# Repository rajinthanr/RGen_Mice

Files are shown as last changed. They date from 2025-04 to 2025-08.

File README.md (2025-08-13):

# 🐭 Open Source Micromouse Project

Welcome to the official repository of our **Open Source Micromouse** - a fast, intelligent, and compact maze-solving robot developed from scratch by [rajinthan](https://github.com/rajinthanr). This project aims to document every step of the design and development process, making it easy for students, hobbyists, and engineers to learn and contribute.

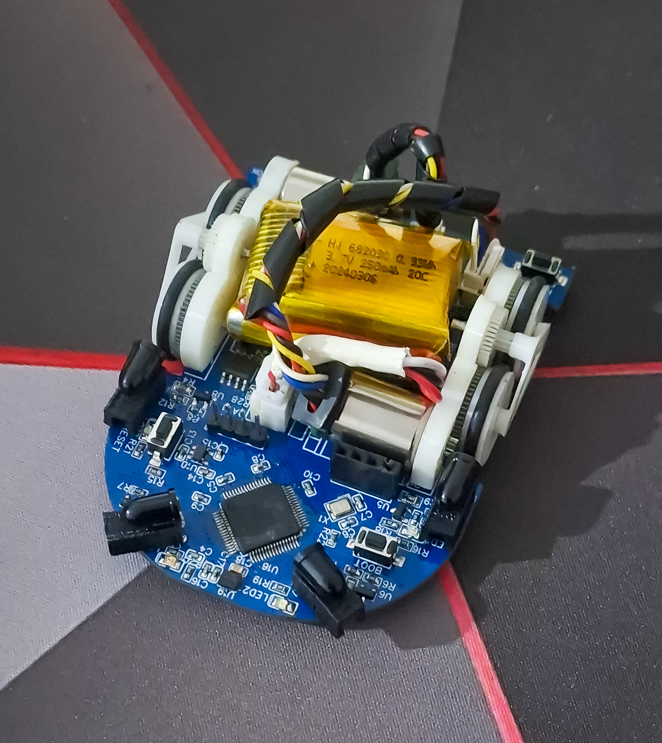
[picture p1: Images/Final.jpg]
Micromouse Design


---

## 🚀 Project Goal

To design and develop a **four-wheel differential drive Micromouse robot** capable of solving mazes efficiently with smooth acceleration, encoder feedback, and intelligent path planning — while maintaining openness for community learning and contribution.

---

## 🧭 Table of Contents

- [🔍 Research & Reference Designs](#-research--reference-designs)
- [🧩 Component Selection](#-component-selection)
- [📐 Mechanical Design](#-mechanical-design)
- [⚙️ Drive System](#️-drive-system)
- [🔌 Electronics & PCB Design](#-electronics--pcb-design)
- [📦 Firmware Development](#-firmware-development)
- [🧠 Algorithms & Strategy](#-algorithms--strategy)
- [🖥️ Simulation](#️-simulation)
- [📸 Gallery](#-gallery)
- [📚 Resources](#-resources)
- [🤝 Contributing](#-contributing)
- [📜 License](#-license)

---

## 🔍 Research & Reference Designs

Before jumping into development, we explored multiple Micromouse designs, performance benchmarks, and open-source efforts.

- [Ukmars](https://ukmars.org/)
- [Greenye](https://youtube.com/@greenye?si=StKEDgfJgn1EC-rX)(Good youtube channel)
- [Micromouse Online Handbook](https://micromouseonline.com/)
- [Speed Profile](https://micromouseonline.com/2017/08/03/micromouse-hard-acceleration/)

### 📄 Design Inspirations

- Green-Giant

*Reference images:*

| Reference Design 1 | Reference Design 2 |
|---|---|
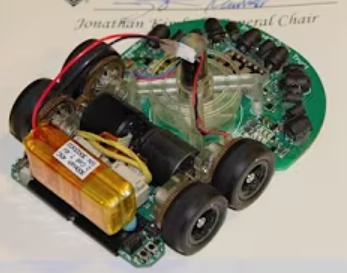
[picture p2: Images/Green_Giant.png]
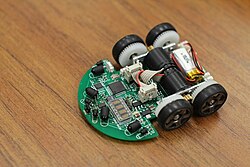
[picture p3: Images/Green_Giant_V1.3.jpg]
|  |  |

---

## 🧩 Component Selection

Every part was chosen with precision to balance performance, weight, and efficiency.

| Component | Description | Datasheet |
|---|---|---|
| MCU | STM32F405 (ARM Cortex-M4) | [Datasheet](https://www.st.com/resource/en/datasheet/dm00037051.pdf) |
| Motors | Coreless Motor 1215 with quadrature magnetic encoders | [Datasheet](//) |
| Encoders | Builtin quadrature magnetic encoders | - |
| IMU | ICM-42688 | [Datasheet](https://invensense.tdk.com/download-pdf/icm-42688-p-datasheet/) |
| Sensors | TEFT4300 IR sensors | [Datasheet](https://www.digikey.com/en/products/detail/vishay-semiconductor-opto-division/TEFT4300/1681175) |
| Power | 2S Li-po 250mAh | - |

> 💡 *Includes datasheets for all components in the `Research/Datasheets` folder.*
---

## 📐 Mechanical Design

- Designed in **Onshape**
- Lightweight 3D printable chassis
- Wheel size, placement optimized for turn radius

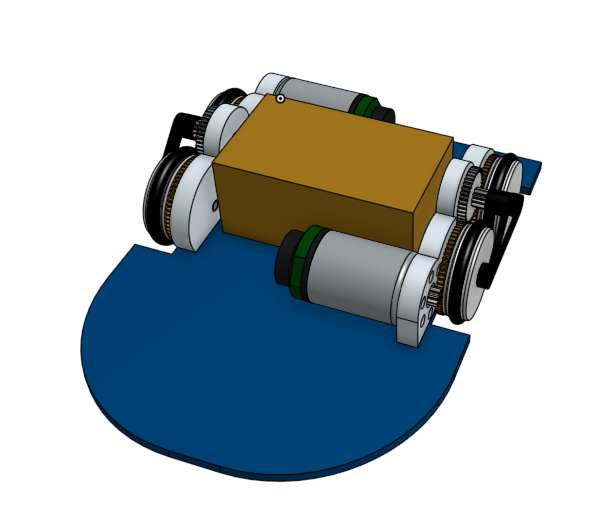
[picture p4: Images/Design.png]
Chassis render


> 💡 *Includes STL files for all parts in the `Design/` folder.*

---

## ⚙️ Drive System

- **Differential drive** with PID-based velocity control
- Closed-loop motor control using encoders
- Acceleration curve implemented to avoid overshoot

### Drive Tuning

- ✔️ Encoder feedback integrated
- ✔️ PWM control through timer
- ✔️ Slew rate limiter for smooth turns

### Design Itterations

|V1|V2|V3|
|----|----|----|
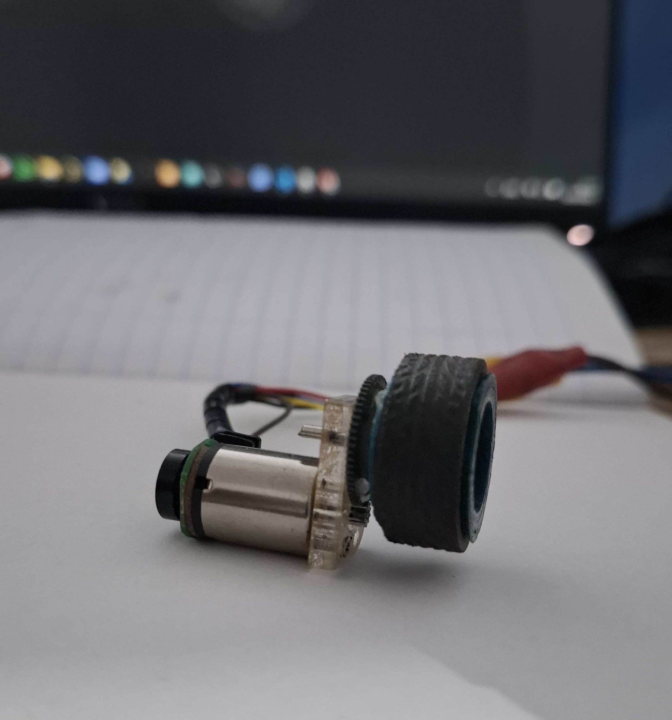
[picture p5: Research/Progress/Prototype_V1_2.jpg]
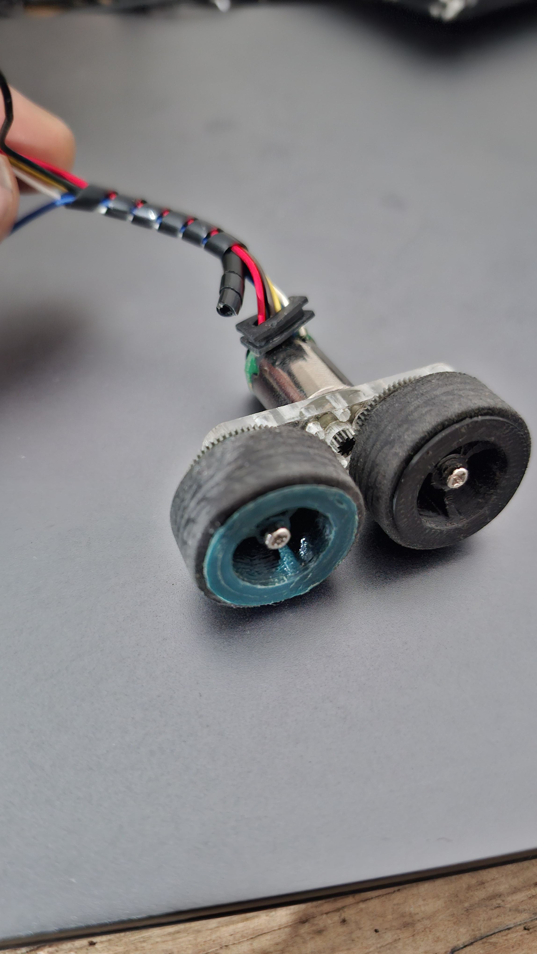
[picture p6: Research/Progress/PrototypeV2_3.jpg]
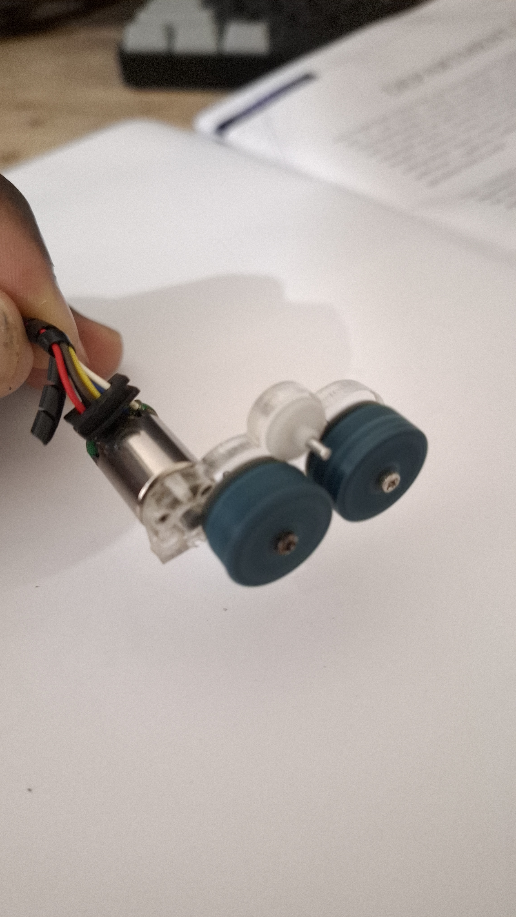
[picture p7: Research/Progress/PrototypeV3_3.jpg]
||||

---

## 🔌 Electronics & PCB Design

Designed using **Easy EDA** - free tool for beginners, our custom 2-layer PCB includes:

- STM32F405 MCU
- Power ICs
- Motor, Encoder and Power connectors
- Motor drivers (DRV8833)
- Programming header (SWD)

| Design | Soldered |
|---|---|
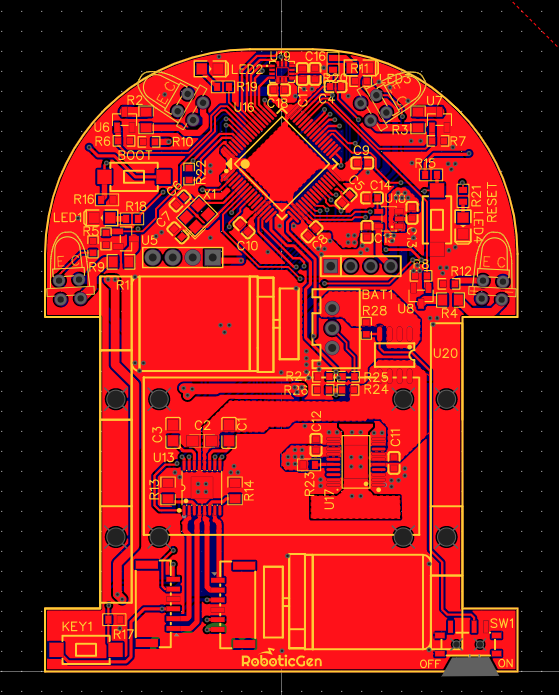
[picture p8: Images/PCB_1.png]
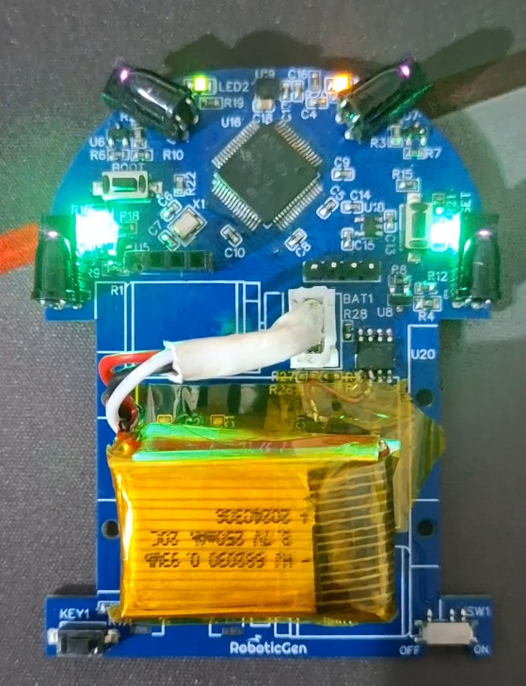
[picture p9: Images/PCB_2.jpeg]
|  |  |

```bash
# PCB files and Gerbers:
PCB/
├── BOM.csv
├── micromouse.sch
└── gerbers/

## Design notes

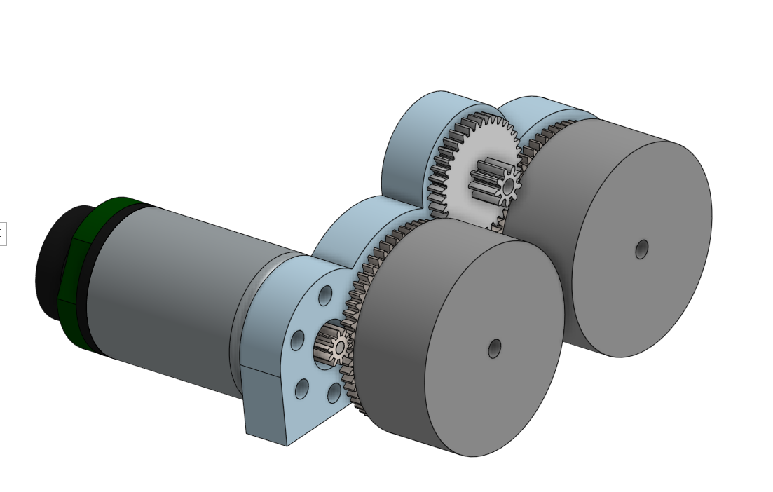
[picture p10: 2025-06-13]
Research/Progress/3D DesignV3.png

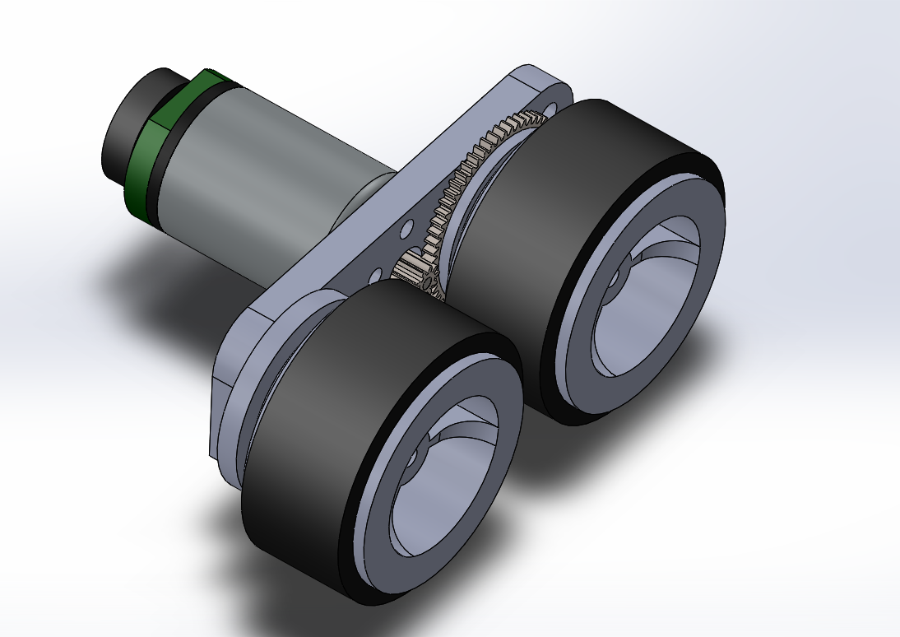
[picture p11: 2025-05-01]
Research/Progress/3D DesignV2.png

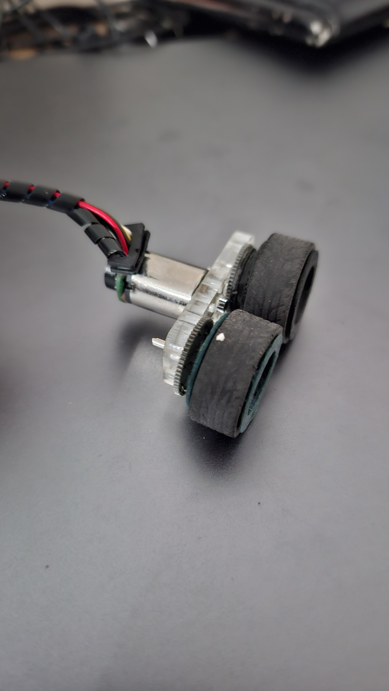
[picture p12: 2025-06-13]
Research/Progress/PrototypeV2_1.jpg

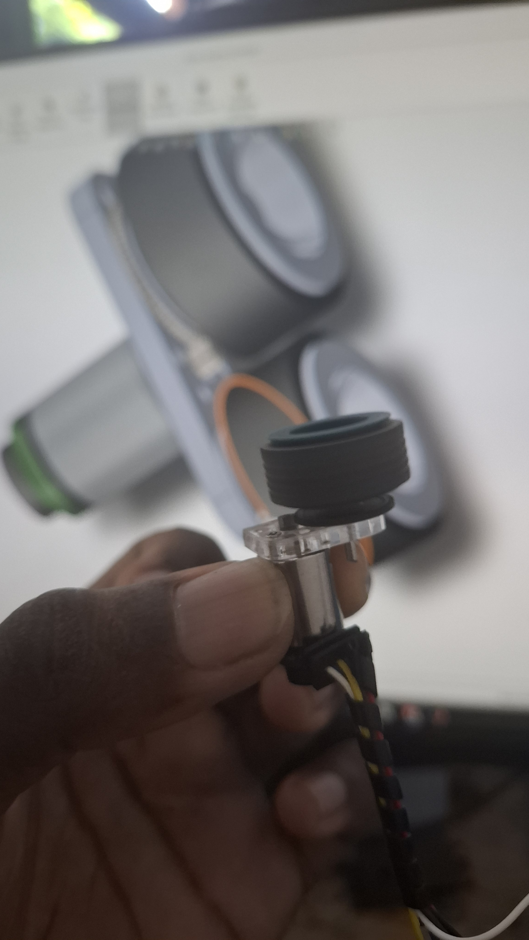
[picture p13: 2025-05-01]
Research/Progress/Prototype_V1_1.jpg

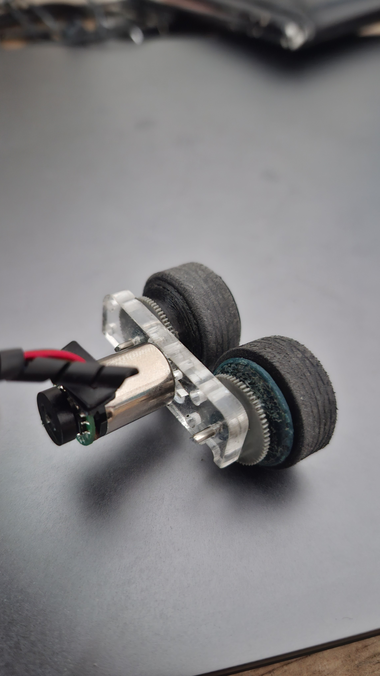
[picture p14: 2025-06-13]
Research/Progress/PrototypeV2_2.jpg

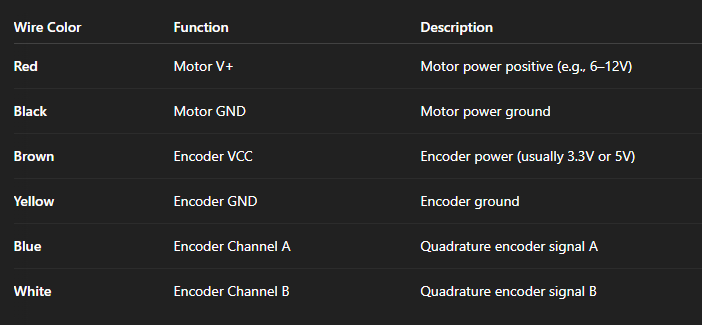
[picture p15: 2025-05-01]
Research/Datasheets/image.png

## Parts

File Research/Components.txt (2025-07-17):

MCU
    *stm32f405
        +have enough pins and speed for our micromouse
        -no builtin Wireless debugging options available
        +reliable
        IDE -> stm32CubeIDE

    esp32s3
        -pins are limited
        +builtin BT&WiFi available for debugging
        IDE -> esp-idf & ArduinoIDE

IR
    Emitter
        *SFH4545  (Half angle = 5°)
    Recievers
        TPS601A  (Angle of Half Sensitivity= ±10°) - many japanese mice used this one but it's been discontinued now
        LTR4206E (Angle of Half Sensitivity= ±20°)
        *TEFT4300 (Angle of Half Sensitivity= ±30°) - commonly used one

IMU
    LY3200ALH (Analog Gyro - Single Axis - Rate noise density 0.074 dps/√Hz) - too old, noisy
    (+)ICM-20948 (9-Axis) - good one
    *(+)ICM-42688 - latest (32kHz DRO, low noise)
    ICM-45686
    ADXRS642
    ADXRS300 and ADXRS610
    (+)ASM330LHH (2020 by ST Microelectronics) - 3kHz sampling rate & reliable

Motor Driver
    TC4427 (Mosfet Driver) - need of p-mos means lack of efficency
    zxmhc3f381n8tc (3A Mosfet H-Bridge) - high current rating but bit harder to use
    *DRV8833 (1.5A) - easy to use and compact
    TB67H420FTG (9.0A) - overkill for our mouse and too many pins to solder

Motors
    N20 geared Motors with magnetic encoders
        +Builtin encoders
        +cheaper
        -not accurate
        -not small enough

    Faulhaber
        +Builtin encoders
        -too expensive
        +much accurate
        +Reliable
    
    Steppers
        -Too bulky and power hungry
        -too slow for micromouse
        +Higer Accuracy

    *Coreless Motor 1215 with quadrature magnetic encoders
        +Builtin encoders
        +cheaper
        +smaller
        -not reliable (but enough for our purpose)

Encoders
    It's better to use builtin encoders

Display
    HCMS-2903 - speed and compact but no of characters are limited, expensive
    *SSD1306 (0.96" OLED) - very slow, cheap
    SSD1306 (0.91" OLED) - this is also enough and compact

Power ICs
    *TPS76850 (5V 1A) - low dropout (230mV)
    *TPS73633 (3V3 400mA) - low dropout (76mV)
    AMS1117 (3V3 800mA) - Dropout voltage is high (1V)

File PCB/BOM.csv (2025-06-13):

ID | Name | Designator | Footprint | Quantity | Manufacturer Part | Manufacturer | Supplier | Supplier Part | Price
1 | JST 3 pin | BAT1 | 3PIN_2.54_MM_JST_XHP_JST_CONNECTOR_FOR_DC_SOCKET | 1
2 | 0.01u | C1 | C0805 | 1
3 | 1u | C2 | CASE-A_3216 | 1
4 | 0.1u | C3 | C0805 | 1
5 | 2.2u | C4,C5,C16 | C0603 | 3
6 | 22p | C6,C7 | C0603 | 2
7 | 100n | C8,C9,C10 | C0603 | 3
8 | 100nF | C11,C13,C14,C15 | C0603 | 4 | CA45-A-35V-0.1UF-K | CEC(振华新云) | LCSC | C2976900 | 0.114
9 | 10u | C12 | C0603 | 1
10 | 0.1u | C17 | C0603 | 1
11 | 10n | C18 | C0603 | 1
12 | SW | H1 | HDR-TH_4P-P2.54-V-M | 1 | B-2100S04P-A110 | Ckmtw(灿科盟) | LCSC | C124378 | 0.046
13 | COM | H2 | HEADER-HEADER-FEMALE-2.54_1X4 | 1 |  |  | Private
14 | BOOT | KEY1 | KEY-SMD_L6.0-W3.6-LS8.3-L | 1 | Switch,3*6*5Plastic head,260G, 0.25mm,SMD | BBJ | LCSC | C71854
15 | KEY1 | KEY2 | KEY-SMD_L6.0-W3.6-LS8.3-L | 1 | Switch,3*6*5Plastic head,260G, 0.25mm,SMD | BBJ | LCSC | C71854
16 | RESET | KEY3 | KEY-SMD_L6.0-W3.6-LS8.3-L | 1 | Switch,3*6*5Plastic head,260G, 0.25mm,SMD | BBJ | LCSC | C71854
17 | PWR | KEY4 | SW-TH_6P-L5.8-W5.8-P2.00-LS4.5-TR | 1 |  | ReliaPro | LCSC | C56857
18 | IO18 | LED1,LED2,LED3,LED4 | LED0805_BLUE | 4 | D-B080508B1-KS2 | 方舟 ARKLED |  | C108412 | 0.019
19 | 10 | R1,R2,R3,R4 | R0805 | 4
20 | 10K | R5,R6,R7,R8 | R0603 | 4
21 | 1k | R9,R10,R11,R12 | R0603 | 4
22 | 100m | R13,R14 | R0805 | 2
23 | 10K | R15,R16,R17 | R0603_SMD-CRCW060327R0FKEA | 3
24 | 1K | R18,R19,R20,R21 | R0603_SMD-CRCW060327R0FKEA | 4
25 | 0 | R22 | R0603 | 1
26 | 250k | R23 | R0603_SMD-CRCW060327R0FKEA | 1
27 | 100k | R24 | R0603 | 1
28 | 47K | R25 | R0603 | 1
29 | 47k | R26,R27 | R0603 | 2
30 | FL | U1 | SFH4545 | 1
31 | L | U2 | SFH4545 | 1
32 | R | U3 | SFH4545 | 1
33 | FR | U4 | SFH4545 | 1
34 | AO3400NSA | U5,U6,U7,U8 | SOT-23-3_L2.9-W1.3-P1.90-LS2.4-BR | 4 |  | DOWO(东沃) | LCSC | C5456620 | 0.044
35 | FL | U9 | TEFT4300 | 1
36 | L | U10 | TEFT4300 | 1
37 | R | U11 | TEFT4300 | 1
38 | FR | U12 | TEFT4300 | 1
39 | DRV8833PWP | U13 | TSSOP-16_L5.0-W4.4-P0.65-LS6.4-BL-EP | 1 |  | TI(德州仪器) | LCSC | C50506 | 0.705
40 | MOTA | U14 | CONN-SMD_6P-P1.25_BX-BX-GH1.25-6PLT | 1 | BX-BX-GH1.25-6PLT | Bossie(博锡) | LCSC | C18077713 | 0.113
41 | MOTB | U15 | CONN-SMD_6P-P1.25_BX-BX-GH1.25-6PLT | 1 | BX-BX-GH1.25-6PLT | Bossie(博锡) | LCSC | C18077713 | 0.113
42 | TPS76850QPWP | U17 | HTSSOP-20_L6.5-W4.4-P0.65-LS6.4-BL-EP | 1 | TPS76850QPWP | TI(德州仪器) | LCSC | C139401 | 3.047
43 | TPS73633DBVR | U18 | SOT-23-5_L3.0-W1.7-P0.95-LS2.8-BR | 1 | TPS73633DBVR | TI(德州仪器) | LCSC | C28038 | 0.496
44 | ICM-42688-P | U19 | LGA-14_L3.0-W2.5-P0.50-TL | 1 | ICM-42688-P | TDK InvenSense(应美盛) | LCSC | C1850418 | 2.519
45 | 25MHz | X1 | CRYSTAL-SMD_4P-L3.2-W2.5-BL | 1 | XL2EL89CSI-111YLC-25M | YXC(扬兴晶振) | LCSC | C5280577 | 0.062
46 | STM32F405RGT6 | U16 | LQFP-64_L10.0-W10.0-P0.50-LS12.0-BL | 1 | STM32F405RGT6 | ST(意法半导体) | LCSC | C15742 | 3.51

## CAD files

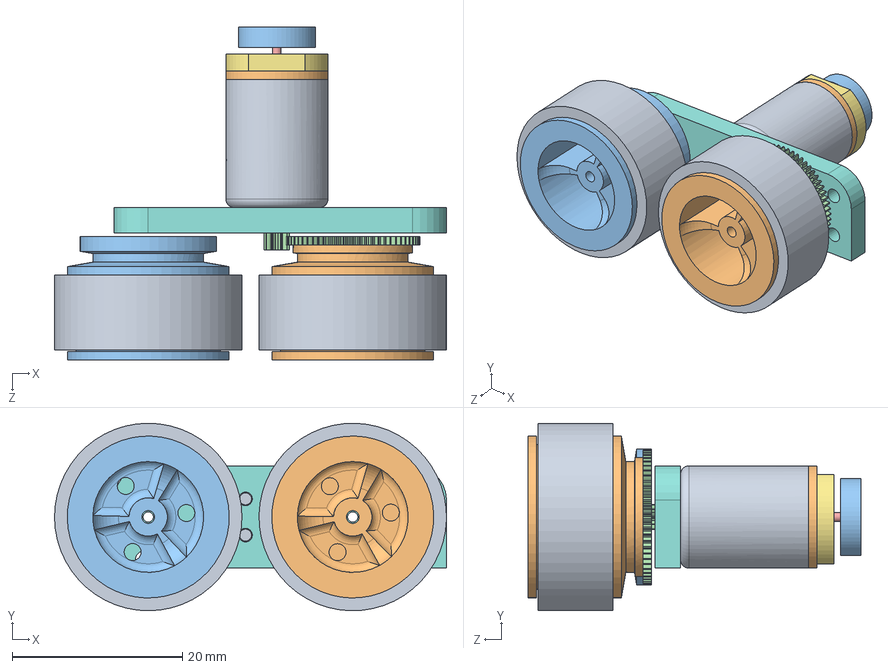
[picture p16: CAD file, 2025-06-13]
Design/Drive System.SLDASM
46.0 x 22.0 x 39.1 mm
back cover
magnet
spur gear_am x 3
rod
brass bearing
PCB
holder
Tyre x 2
Rim
Rim_nogear

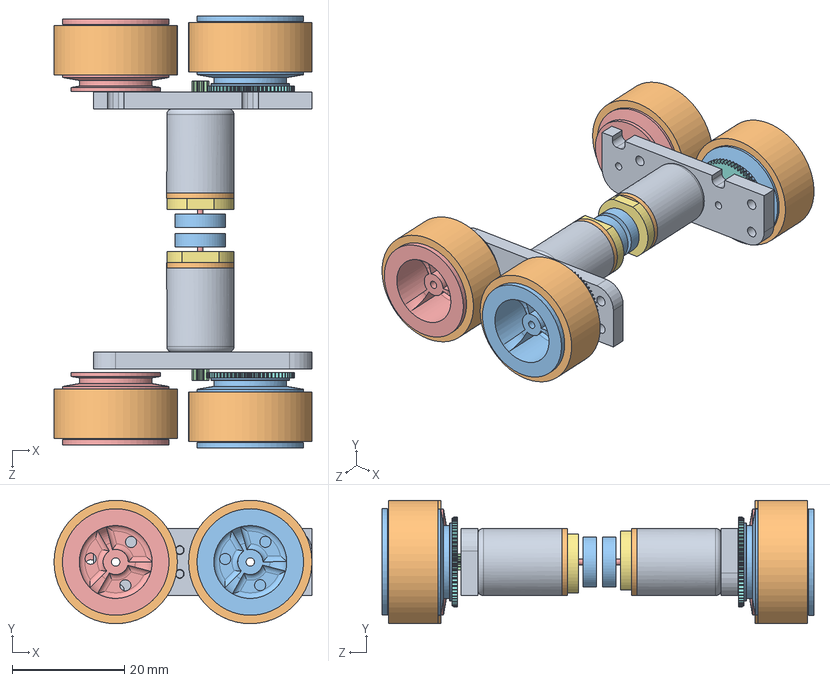
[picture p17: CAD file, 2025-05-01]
Design/Mouse.SLDASM
46.0 x 22.0 x 77.0 mm
back cover x 2
magnet x 2
spur gear_am x 2
rod x 2
brass bearing x 2
PCB x 2
Wheel gear 61T x 2
holder x 2
Tyre x 4
Rim x 2
wheel_subgear x 2
Rim_nogear x 2

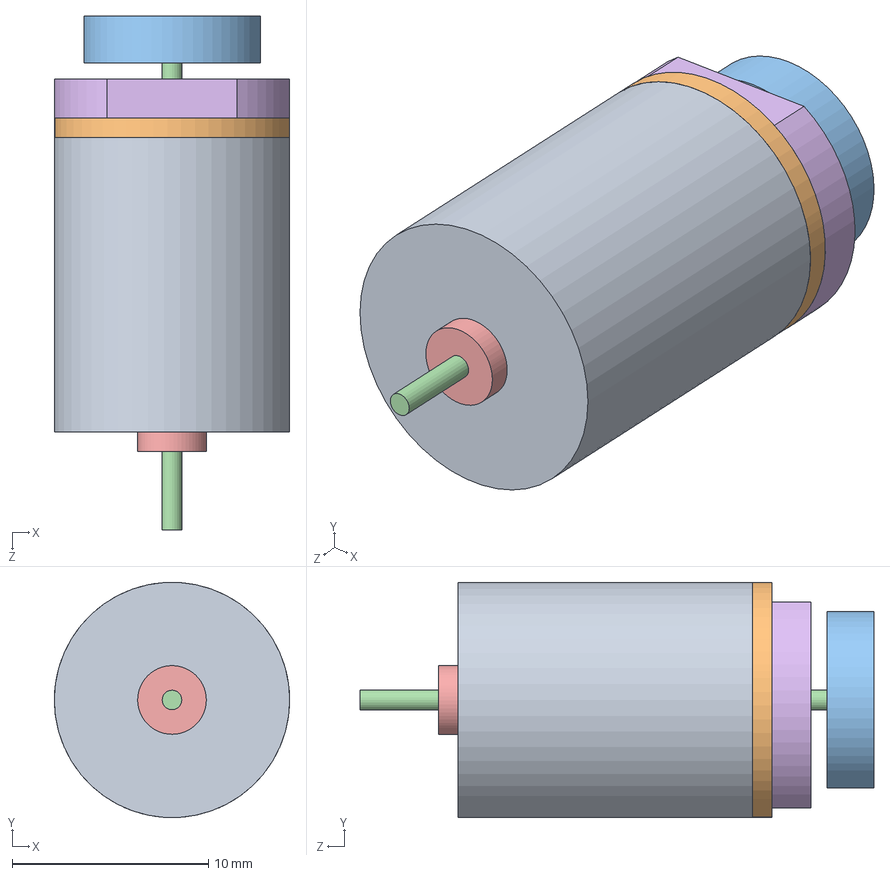
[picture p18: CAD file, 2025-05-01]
Design/Motor1215/Motor.SLDASM
12.0 x 12.0 x 26.2 mm
back cover
magnet
rod
brass bearing
PCB

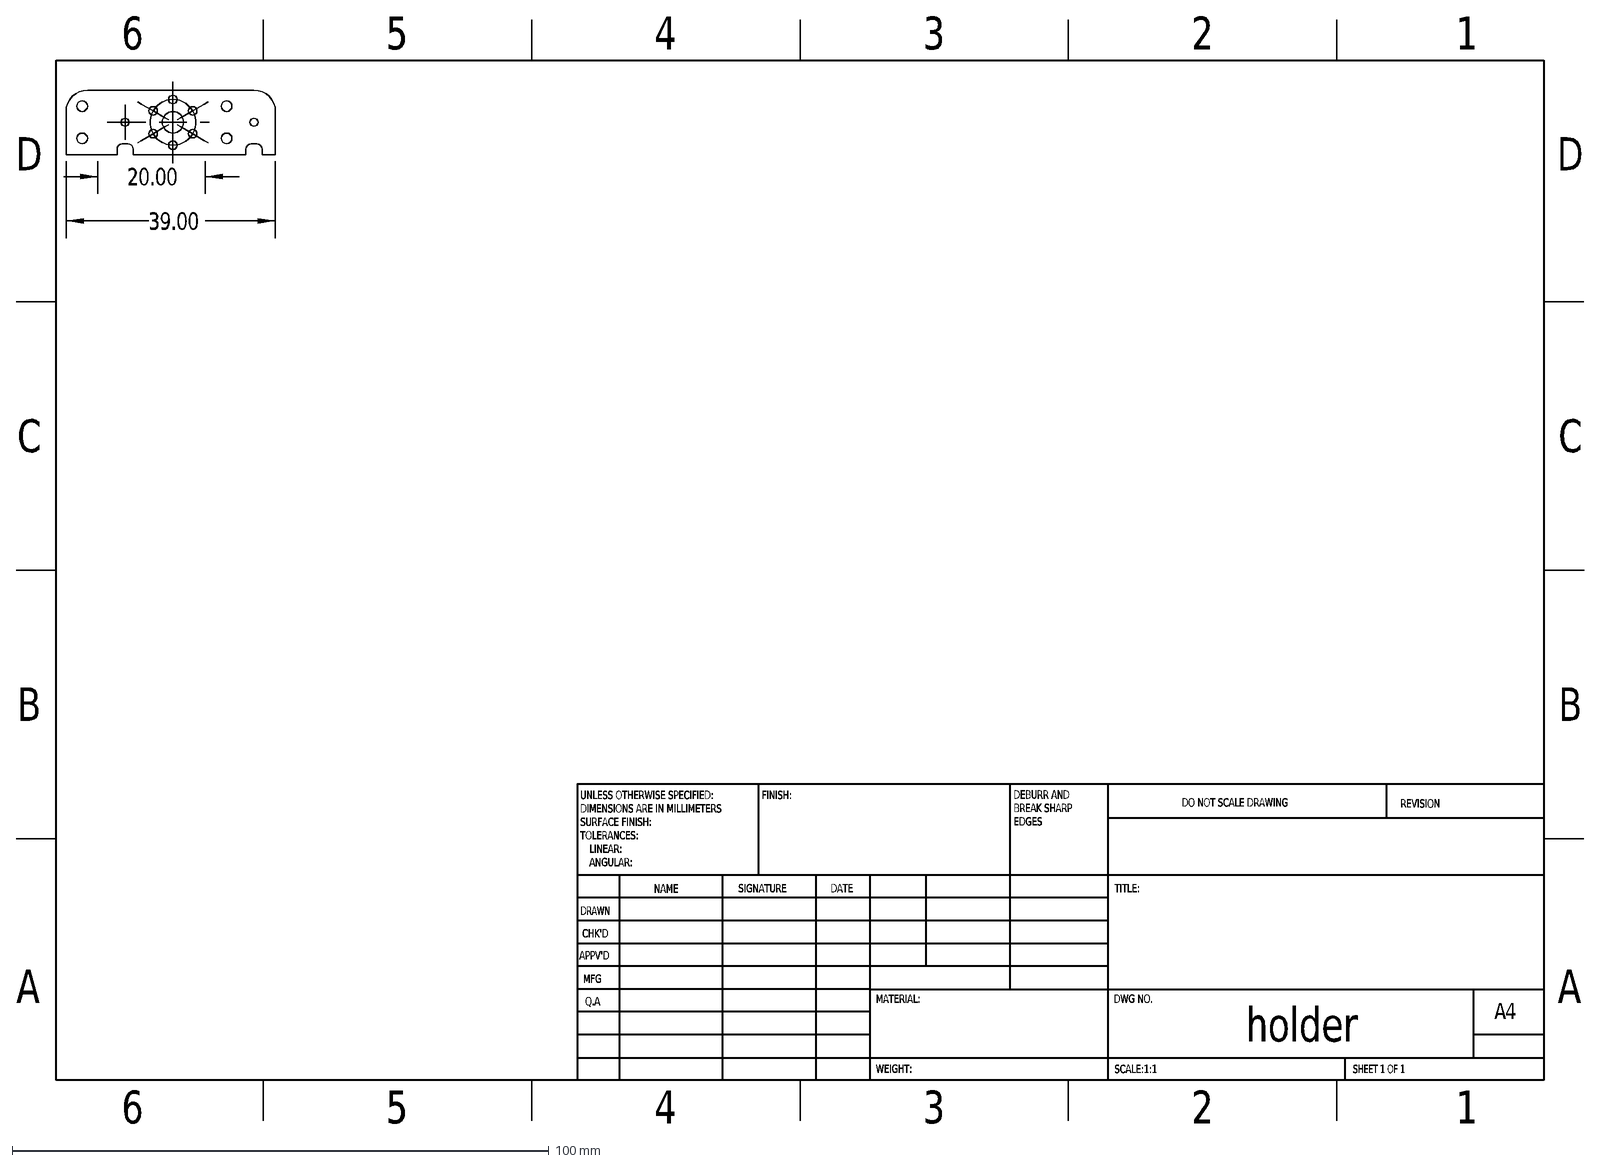
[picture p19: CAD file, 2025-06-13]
Design/holder.DXF
DRAWN
CHK'D
APPV'D
MFG
Q.A
UNLESS OTHERWISE SPECIFIED:
DIMENSIONS ARE IN MILLIMETERS
SURFACE FINISH:
TOLERANCES:
LINEAR:
ANGULAR:
FINISH:
DEBURR AND
BREAK SHARP
EDGES
NAME
SIGNATURE
DATE
MATERIAL:
DO NOT SCALE DRAWING
REVISION
TITLE:
DWG NO.
SCALE:1:1
SHEET 1 OF 1
A4
WEIGHT:
holder
A
B
C
D
6
5
4
3
2
1
20.00
39.00

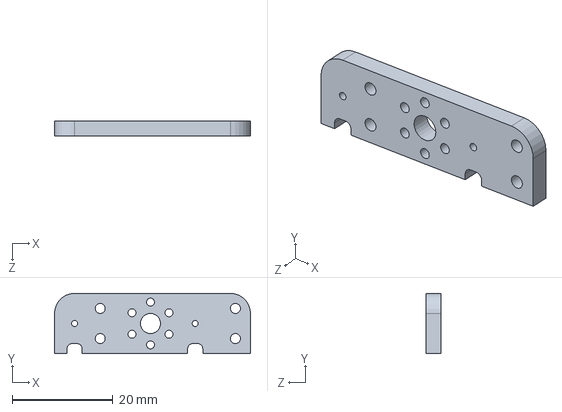
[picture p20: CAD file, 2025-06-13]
Design/Motor1215/holder.SLDPRT
39.0 x 12.0 x 3.00 mm

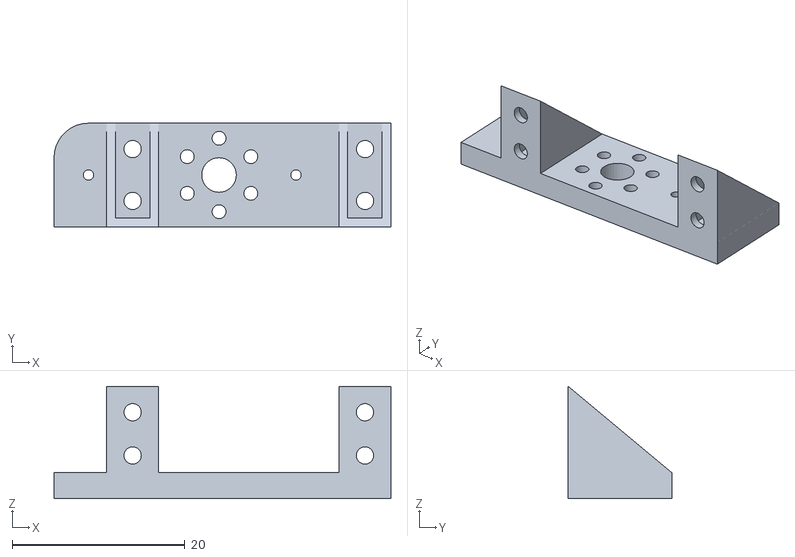
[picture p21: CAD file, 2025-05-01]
Design/prints/holder_3d_print.STL
39.0 x 12.0 x 13.0

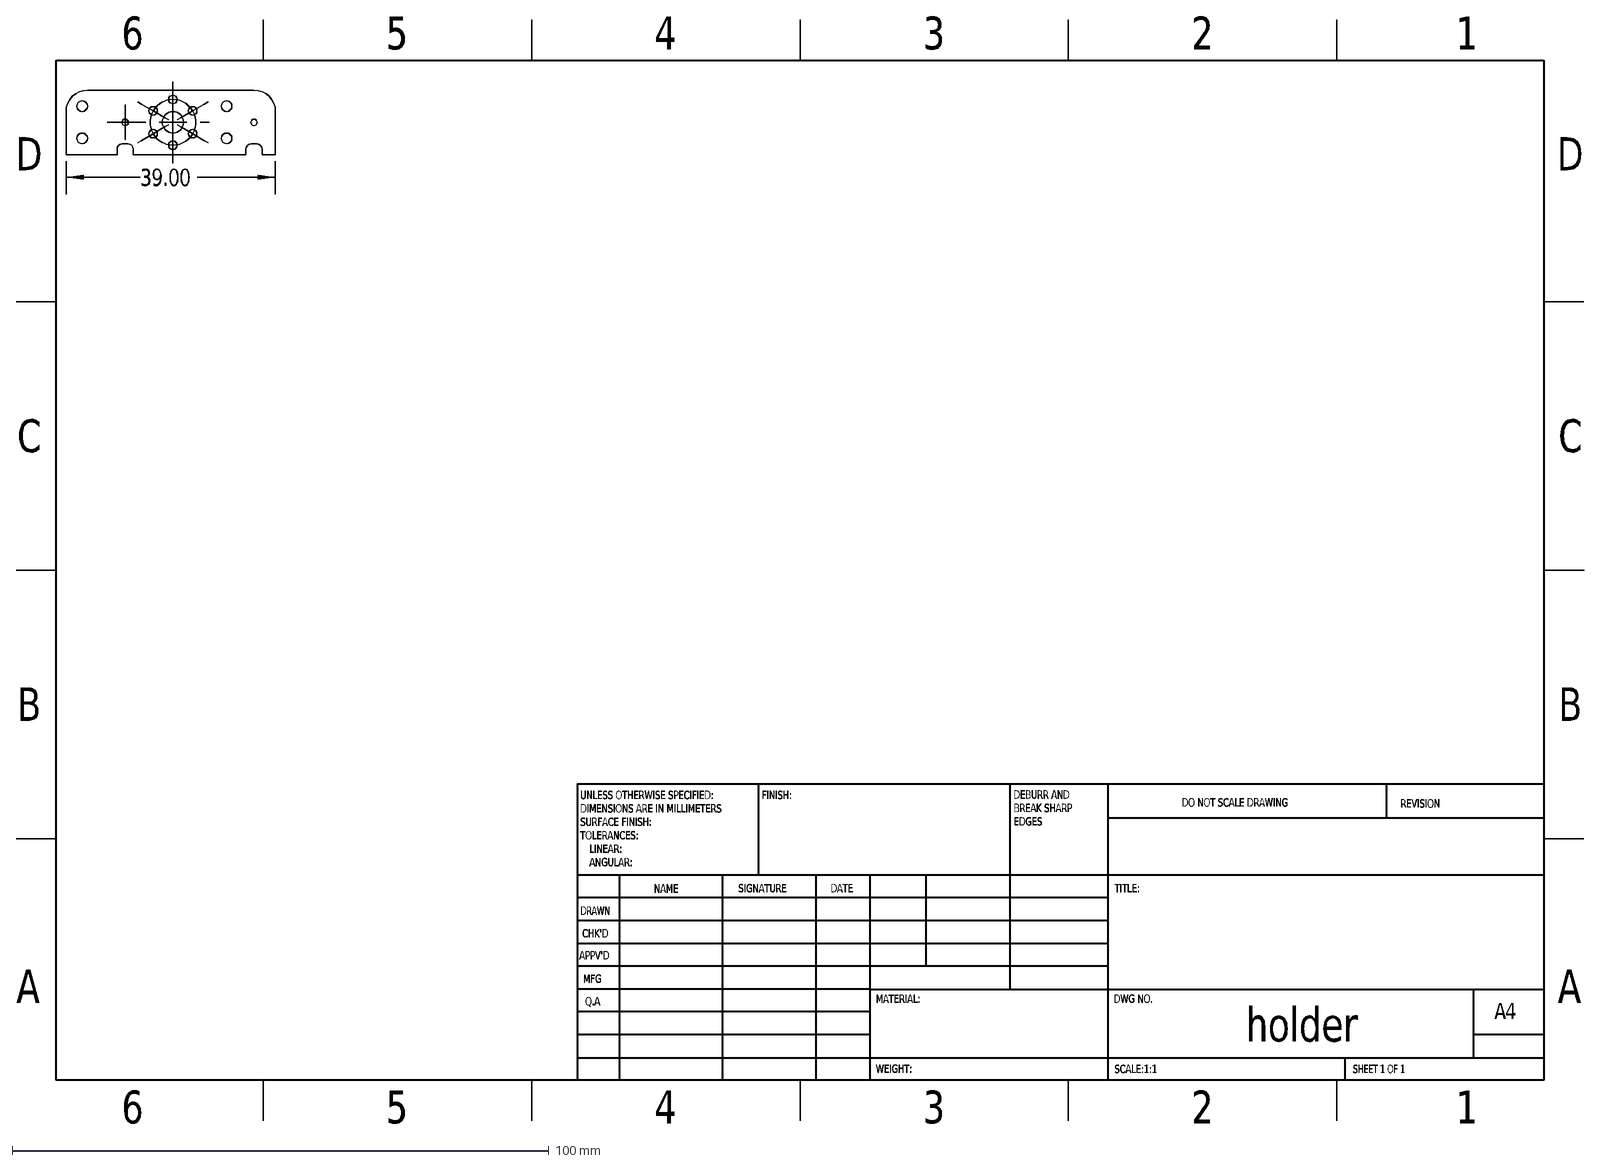
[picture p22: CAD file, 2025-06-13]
Design/holderv2.DXF
DRAWN
CHK'D
APPV'D
MFG
Q.A
UNLESS OTHERWISE SPECIFIED:
DIMENSIONS ARE IN MILLIMETERS
SURFACE FINISH:
TOLERANCES:
LINEAR:
ANGULAR:
FINISH:
DEBURR AND
BREAK SHARP
EDGES
NAME
SIGNATURE
DATE
MATERIAL:
DO NOT SCALE DRAWING
REVISION
TITLE:
DWG NO.
SCALE:1:1
SHEET 1 OF 1
A4
WEIGHT:
holder
A
B
C
D
6
5
4
3
2
1
39.00

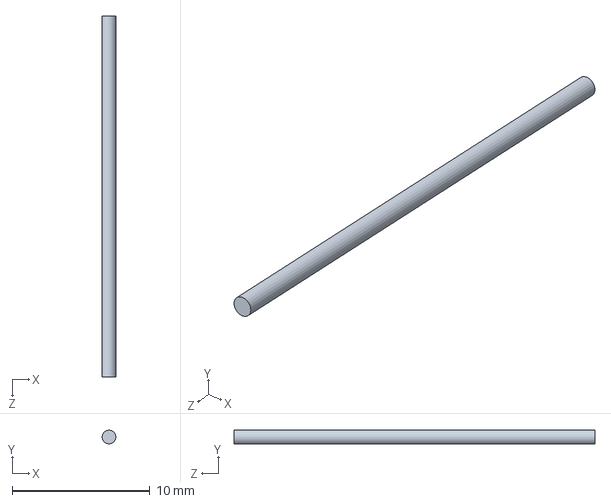
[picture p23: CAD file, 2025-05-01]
Design/Motor1215/rod.SLDPRT
1.00 x 1.00 x 26.2 mm

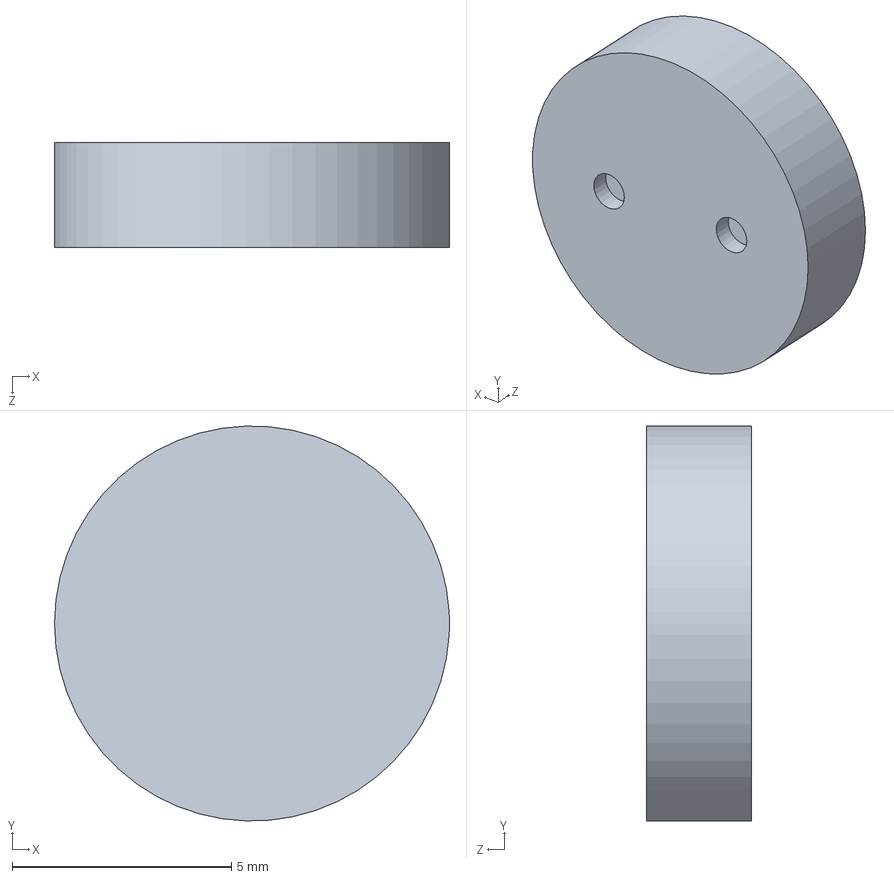
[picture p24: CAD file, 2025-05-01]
Design/Motor1215/magnet.SLDPRT
9.00 x 9.00 x 2.40 mm

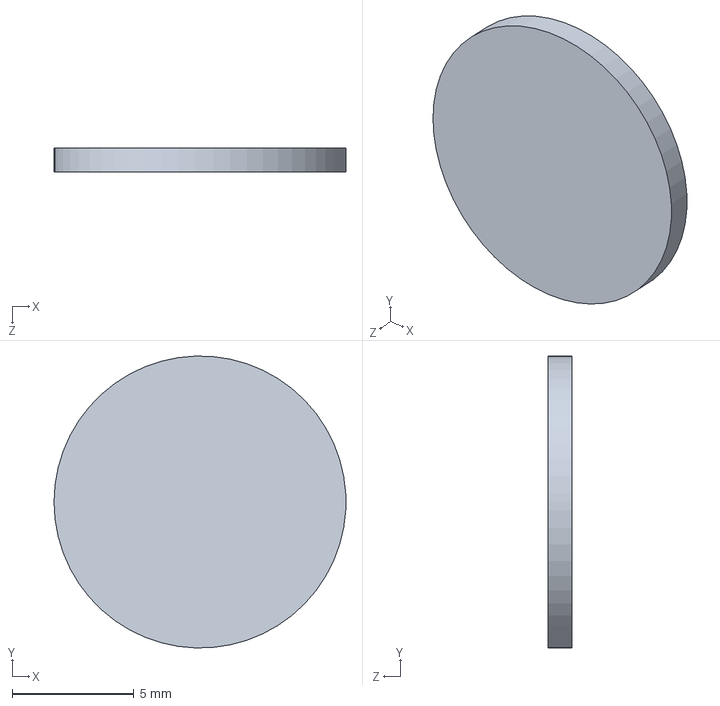
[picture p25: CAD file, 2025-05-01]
Design/Motor1215/back cover.SLDPRT
12.0 x 12.0 x 1.00 mm

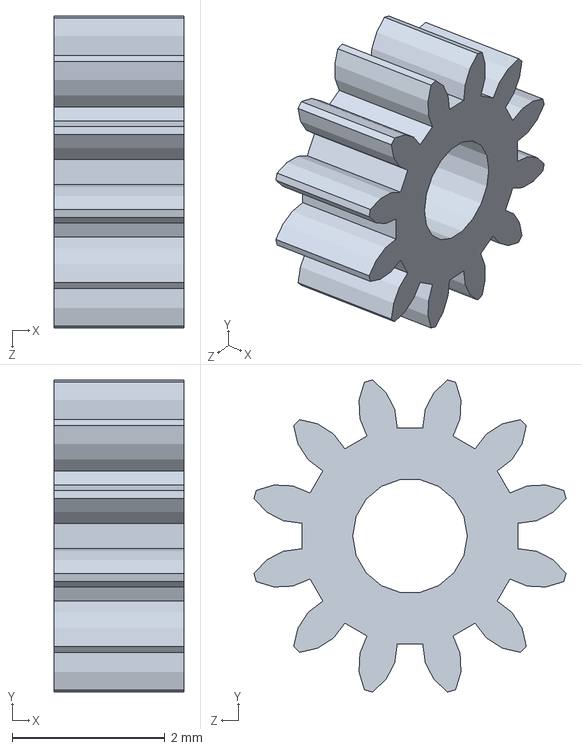
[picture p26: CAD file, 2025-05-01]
Design/wheel_subgear.SLDPRT
1.70 x 4.08 x 4.08 mm

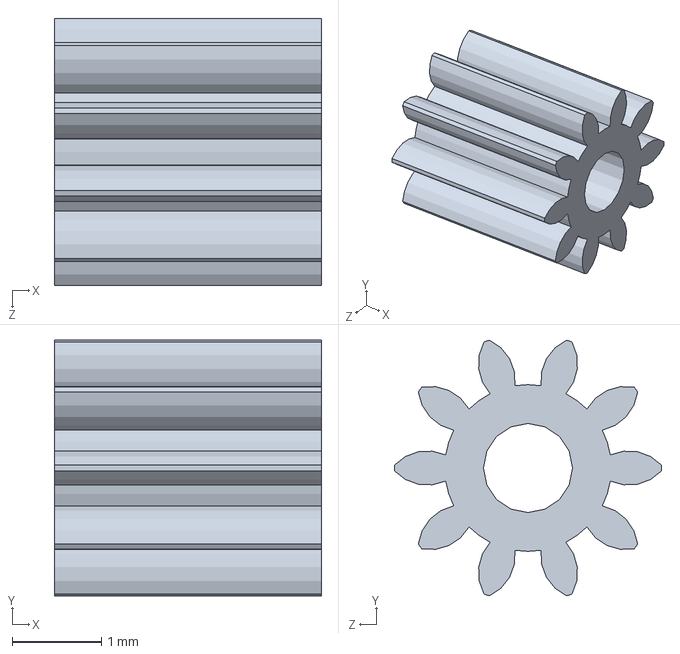
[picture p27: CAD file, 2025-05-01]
Design/Motor gear.SLDPRT
3.00 x 2.87 x 3.00 mm

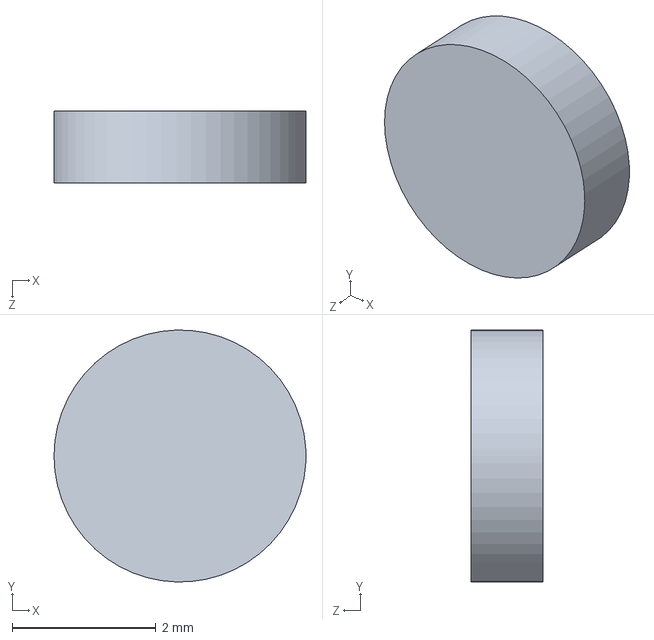
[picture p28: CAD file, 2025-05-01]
Design/Motor1215/brass bearing.SLDPRT
3.50 x 3.50 x 1.00 mm

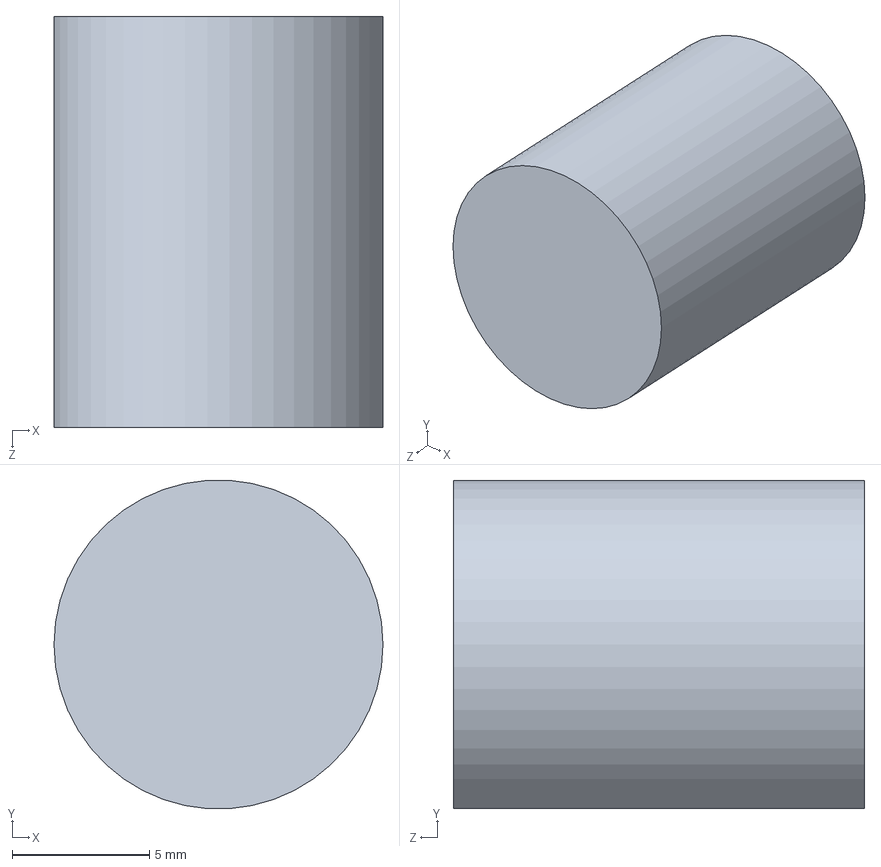
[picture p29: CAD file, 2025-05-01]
Design/Motor1215/Part2.SLDPRT
12.0 x 12.0 x 15.0 mm

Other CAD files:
Design/Motor1215/holder_3d_print.SLDPRT
Design/Tyre.SLDPRT
Design/Motor1215/PCB.SLDPRT
Design/Rim.SLDPRT
Design/Metric - Spur gear 0.25M 60T 20PA 3FW ---S60N75H50L3N.SLDPRT
Design/Motor1215/body.SLDPRT
Design/Motor1215/prints/holder.STL
Design/Motor1215/prints/holder_3d_print.SLDPRT
Design/Rim.STL
Design/Rim_nogear.SLDPRT
Design/Wheel gear 61T.SLDPRT
Design/holder.SLDDRW
Design/motor_gear.DXF
Design/motor_gear.SLDDRW
Design/motor_gear.SLDPRT
Design/prints/Rim.STL
Design/prints/Rim_nogear.STL
Design/prints/washer.STL
Design/washer.SLDPRT

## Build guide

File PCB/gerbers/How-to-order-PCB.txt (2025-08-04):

How to Order PCB

Please refer to:
https://docs.easyeda.com/en/PCB/Order-PCB

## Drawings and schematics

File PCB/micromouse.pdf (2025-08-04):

# IR Transmitter & Reciever

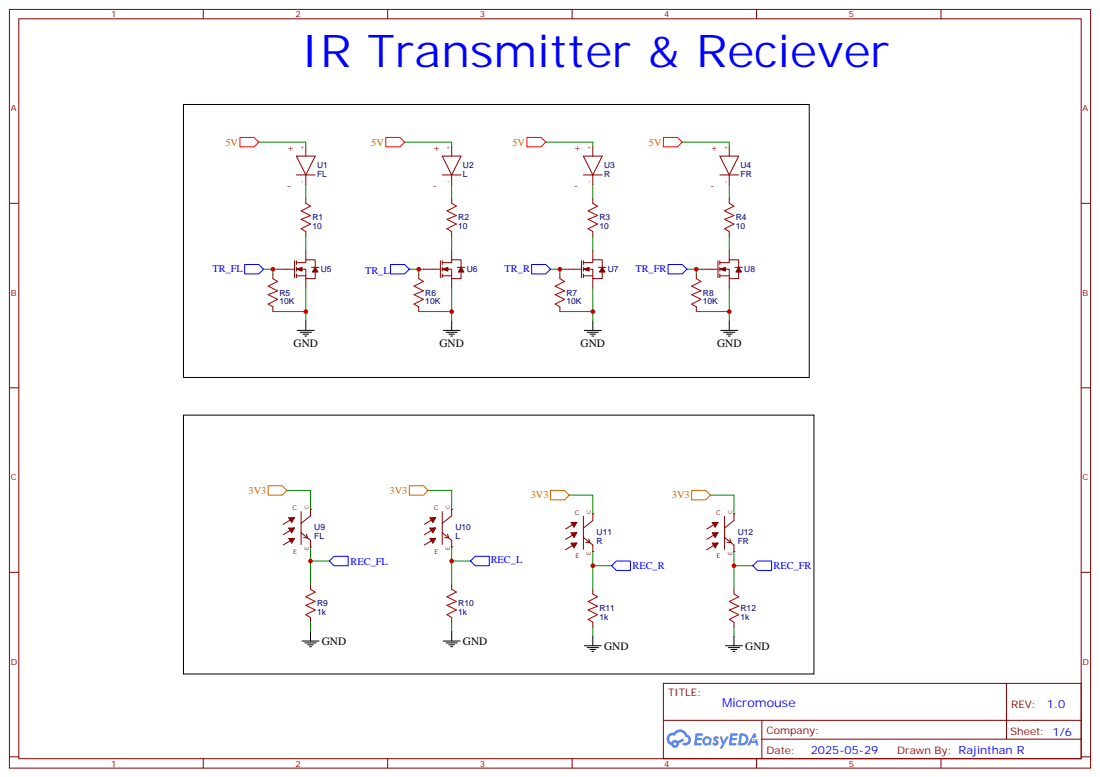
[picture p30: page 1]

# Motor

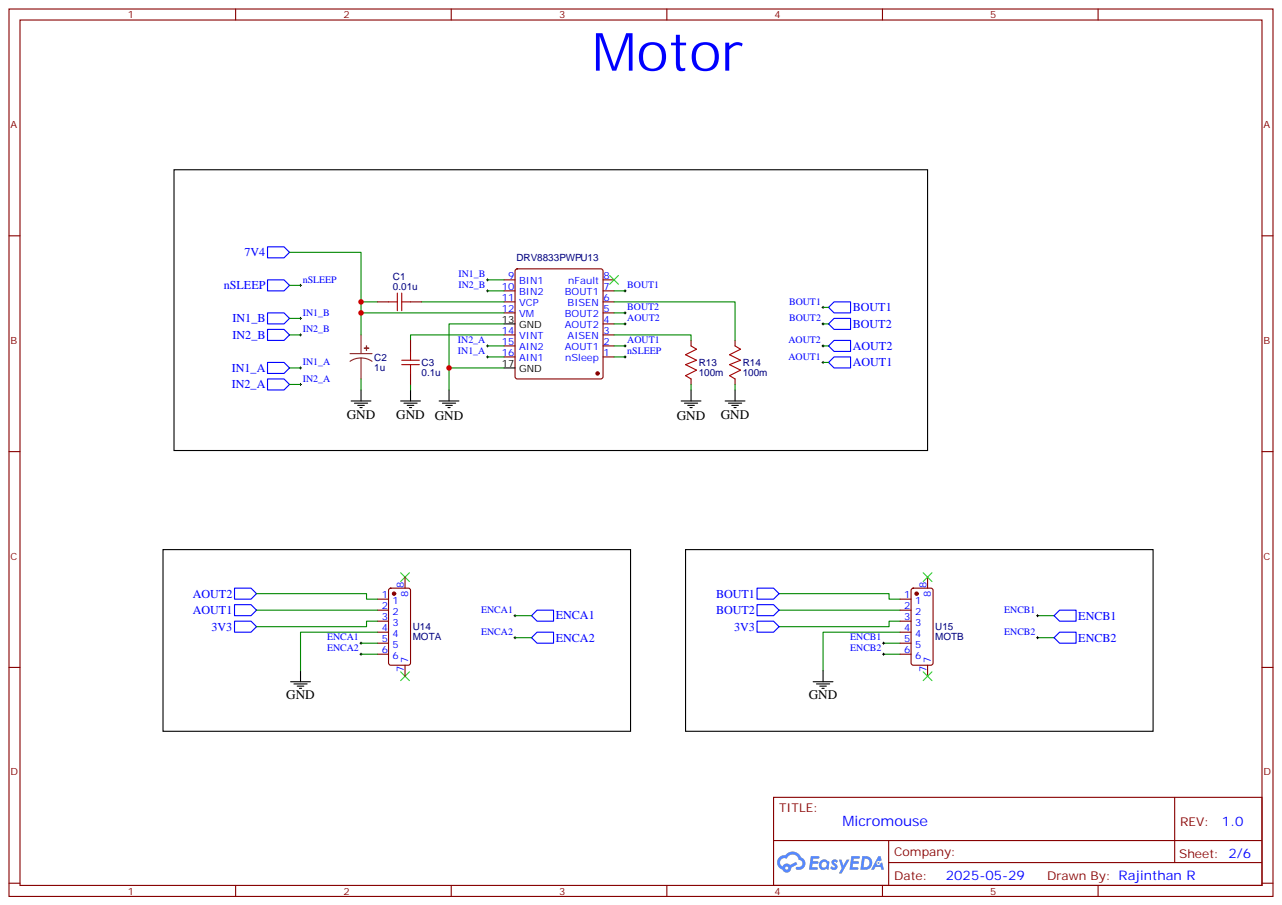
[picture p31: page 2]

# I/Os

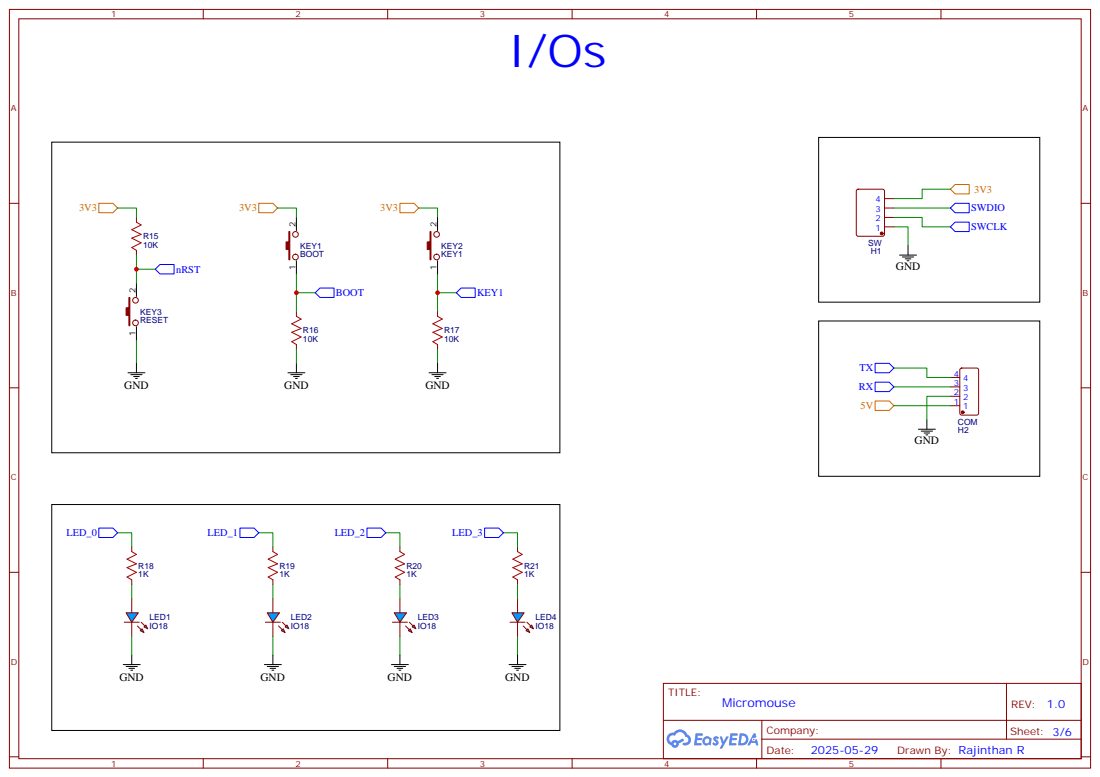
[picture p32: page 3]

# Microcontroller

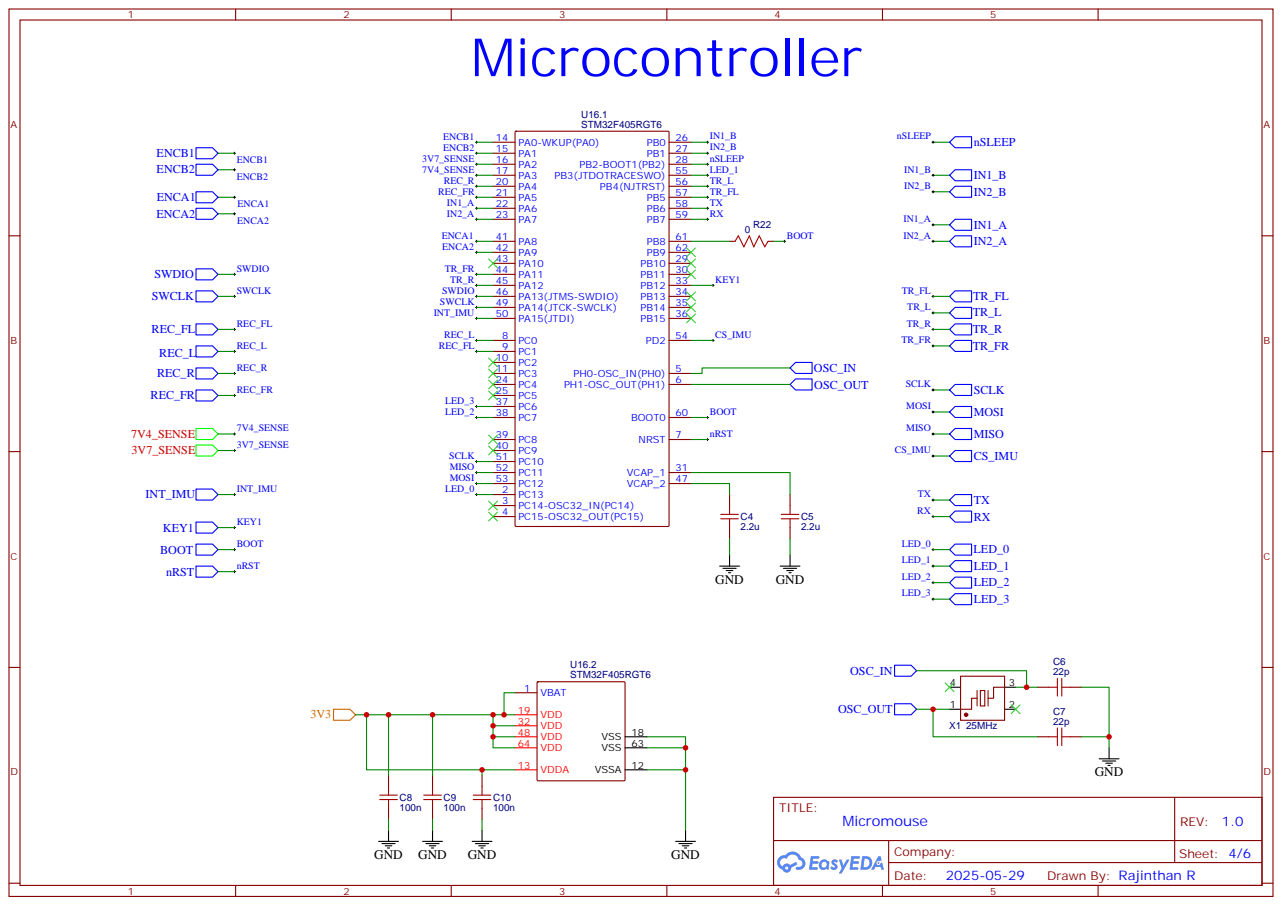
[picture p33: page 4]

# Power System

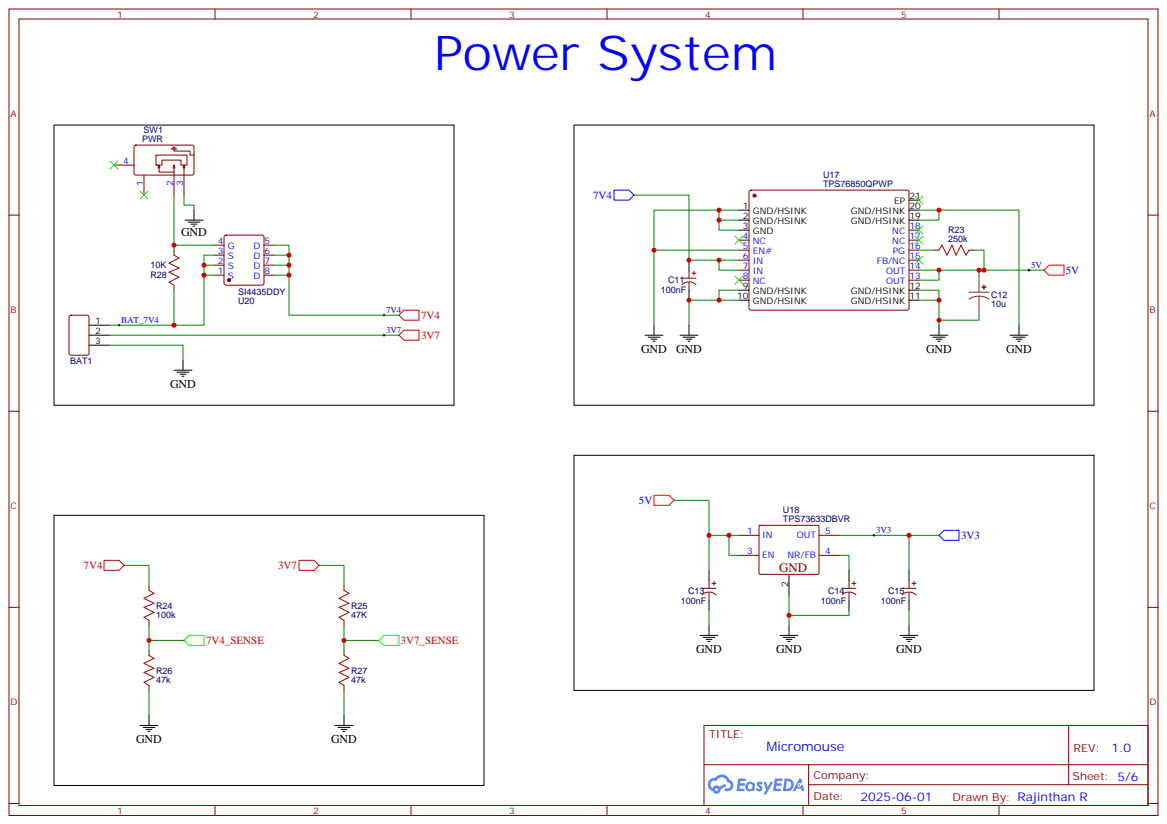
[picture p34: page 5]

# IMU Unit

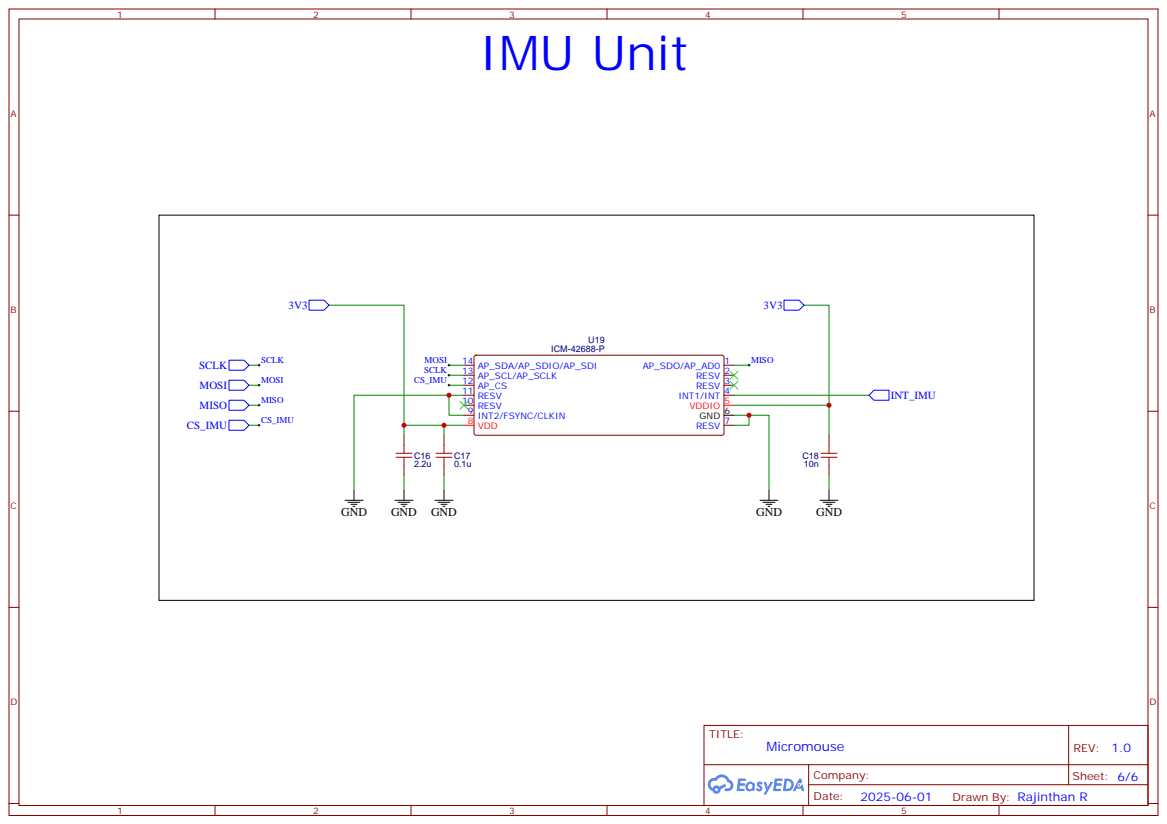
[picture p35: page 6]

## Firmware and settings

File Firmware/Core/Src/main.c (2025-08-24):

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
/* Includes ------------------------------------------------------------------*/
#include "main.h"

/* USER CODE BEGIN Includes */

#include "core.h"
#include "stdio.h"
#include "usart.h"

// #include "icm.h"
// #include "interface.h"
// #include "drive.h"

/* USER CODE END Includes */

ADC_HandleTypeDef hadc1;
ADC_HandleTypeDef hadc2;

SPI_HandleTypeDef hspi3;

TIM_HandleTypeDef htim1;
TIM_HandleTypeDef htim2;
TIM_HandleTypeDef htim3;
TIM_HandleTypeDef htim10;

UART_HandleTypeDef huart1;

/* USER CODE BEGIN PV */

int32_t left_enc;
int32_t right_enc;

float left_speed;
float right_speed;

// Redirect printf to UART
int __io_putchar(int ch)
{
  static uint8_t buffer[100];
  static int ptr = 0;
  buffer[ptr++] = ch;
  if (ch == '\n')
  {
    if (huart1.gState == HAL_UART_STATE_READY)
      HAL_UART_Transmit_IT(&huart1, (uint8_t *)&buffer, ptr);
    ptr = 0;
  }
  return ch;
}
/* USER CODE END PV */

void SystemClock_Config(void);
static void MX_GPIO_Init(void);
static void MX_TIM2_Init(void);
static void MX_TIM1_Init(void);
static void MX_SPI3_Init(void);
static void MX_ADC1_Init(void);
static void MX_ADC2_Init(void);
static void MX_USART1_UART_Init(void);
static void MX_TIM3_Init(void);
static void MX_TIM10_Init(void);
/**
 * @brief  The application entry point.
 * @retval int
 */
int main(void)
{

  /* MCU Configuration--------------------------------------------------------*/

  /* Reset of all peripherals, Initializes the Flash interface and the Systick. */
  HAL_Init();

  /* Configure the system clock */
  SystemClock_Config();

  /* Initialize all configured peripherals */
  MX_GPIO_Init();
  MX_TIM2_Init();
  MX_TIM1_Init();
  MX_SPI3_Init();
  MX_ADC1_Init();
  MX_ADC2_Init();
  MX_USART1_UART_Init();
  MX_TIM3_Init();
  MX_TIM10_Init();
  /* USER CODE BEGIN 2 */

  HAL_TIM_Base_Start(&htim10);

  drive_enable();

  return core(); // core functionality is here :)

  /* USER CODE END 2 */

  /* Infinite loop */
  /* USER CODE BEGIN WHILE */
  while (1)
  {
    /* USER CODE END WHILE */

    /* USER CODE BEGIN 3 */
  }
  /* USER CODE END 3 */
}

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


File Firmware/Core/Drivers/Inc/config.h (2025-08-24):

#ifndef CONFIG_H
#define CONFIG_H

#define NAME "CORE"

struct TurnParameters
{
  int speed;        // mm/s    - constant forward speed during turn
  int entry_offset; // mm      - distance from turn pivot to turn start
  int exit_offset;  // mm      - distance from turn pivot to turn end
  float angle;      // deg     - total turn angle
  float omega;      // deg/s   - maximum angular velocity
  float alpha;      // deg/s/s - angular acceleration
  int trigger;      //         - front sensor value at start of turn
};

//***** SENSOR CALIBRATION **************************************************//
/**
RAW side sensor values when robot is centred in a cell and no wall ahead

##                            ##
||                            ||
||                            ||
||          ______            ||
||         /       \          ||
||         |       |          ||
||         |||   |||          ||
||         |       |          ||
||         |_______|          ||
##============================##

RAW values for the front sensor when the robot is backed up to a wall

##=============================##


             ______
           /       \
           |       |
           |||   |||
           |       |
           |_______|
##=============================##
*/

#if EVENT == EVENT_HOME
// wall sensor thresholds and constants
// RAW values for the front sensor when the robot is backed up to a wall
// with another wall ahead
const int FRONT_LEFT_CALIBRATION = 85;
const int FRONT_RIGHT_CALIBRATION = 90;
// RAW values for the side sensors when the robot is centered in a cell
// and there is no wall ahead
const int LEFT_CALIBRATION = 110;
const int RIGHT_CALIBRATION = 80;

// The front linear constant is the value of k needed to make the function
// sensors.get_distance(sensor,k) return 68 when the mouse is backed up
// against a wall with only a wall ahead
const int FRONT_LINEAR_CONSTANT = 1030;
const int FRONT_REFERENCE = 850; // reading when mouse centered with wall ahead

// SS90E turn thresholds. This is the front sum reading to trigger a turn
// it changes a bit if there is an adjacent wall. The threshold is set for
// when the robot is 20mm past the cell boundary. That is, the distance
// from the front of the mouse to the wall ahead is 92mm
const int TURN_THRESHOLD_SS90E = 82;
const int EXTRA_WALL_ADJUST = 5;

const float FULL_CELL = 180.0f;
const float HALF_CELL = FULL_CELL / 2.0;

const int BACK_WALL_TO_CENTER = 48;

#elif EVENT == EVENT_UK
// RAW values for the front sensor when the robot is backed up to a wall
const int FRONT_LEFT_CALIBRATION = 77;
const int FRONT_RIGHT_CALIBRATION = 34;
// RAW side sensor values when robot is centred in a cell and no wall ahead
const int LEFT_CALIBRATION = 75;
const int RIGHT_CALIBRATION = 72;

// The front linear constant is the value of k needed to make the function
// sensors.get_distance(sensor,k) return 68 when the mouse is backed up
// against a wall with only a wall ahead
const int FRONT_LINEAR_CONSTANT = 1030;
const int FRONT_REFERENCE = 1286; // reading when mouse centered with wall ahead

// SS90E turn thresholds. This is the front sum reading to trigger a turn
// it changes a bit if there is an adjacent wall. The threshold is set for
// when the robot is 20mm past the threshold.
const int TURN_THRESHOLD_SS90E = 110;
const int EXTRA_WALL_ADJUST = 6;

#endif
const float WHEEL_DIAMETER = 31.03;
const float ENCODER_PULSES = 12.00;
const float GEAR_RATIO = 19.540;

// Mouse radius is the distance between the contact patches of the drive wheels.
// A good starting approximation is half the distance between the wheel centres.
// After testing, you may find the working value to be larger or smaller by some
// small amount. AFTER you have the wheel diameter and gear ratio calibrated,
// have the mouse turn in place and adjust the MOUSE_RADIUS until these turns are
// as accurate as you can get them
const float MOUSE_RADIUS = 54 / 2; // 39.50; // Adjust on test

// The robot is likely to have wheels of different diameters or motors of slightly
// different characteristics and that must be compensated for if the robot is to
// reliably drive in a straight line.
// This number adjusts the encoder count and must be  added to the right
// and subtracted from the left motor.
const float ROTATION_BIAS = 0.000; // Negative makes robot curve to left

// Now we can pre-calculate the key constats for the motion control
const float MM_PER_COUNT = 3.141 * WHEEL_DIAMETER / (ENCODER_PULSES * GEAR_RATIO);
const float MM_PER_COUNT_LEFT = (1 - ROTATION_BIAS) * MM_PER_COUNT;
const float MM_PER_COUNT_RIGHT = (1 + ROTATION_BIAS) * MM_PER_COUNT;
const float DEG_PER_MM_DIFFERENCE = (180.0 / (2 * MOUSE_RADIUS * 3.141));

//*** MOTION CONTROLLER CONSTANTS **********************************************//
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

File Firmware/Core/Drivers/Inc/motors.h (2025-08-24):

#ifndef MOTORS_H
#define MOTORS_H

#include "core.h"
#include "math.h"
#include "config.h"
#include "encoder.h"
#include "drive.h"
#include "main.h"
#include "delay.h"
#include "adc.h"
#include "led.h"
#include "sensor_Function.h"
#include "encoder.h"
#include "icm.h"
#include "drive.h"
#include "usart.h"
#include "flash.h"
#include "wall_handle.h"

#define RADIANS_PER_DEGREE 0.017453292519943295 // PI / 180

/***
 * The Motors class is provided with two main control signals - the forward
 * and rotary speeds. A third input come from the steering correction mechanism
 * used normally when the robot is tracking a wall or line. That input could also
 * come from a trajectory tracker or a target seeker.
 *
 * UKMARSBOT uses DC motors and, to get best performance with least user effort,
 * a combination of feedforward and feedbackcontrollers is used. While this can
 * seem complex, the user need not be aware of all the details so long as the
 * appropriate system characterisation is done to provide suitable values for the
 * various system constants.
 *
 * Under the hood, there are a pair of position controllers which have their set
 * points continuously updated by the desired speeds. Odometry provides feedback
 * for these controllers. greater reliability and precision would be possible if
 * the odometry had better resolution and if an IMU were available. But, you can
 * get remarkably good results with the limited resources available.
 */

class Motors;

extern Motors motors;

class Motors
{
public:
  /***
   * TODO: the constructor should really get at least the hardware pins
   * to do a safe setup.
   */
  void enable_controllers()
  {
    m_controller_output_enabled = true;
  }

  void disable_controllers()
  {
    m_controller_output_enabled = false;
  }

  void reset_controllers()
  {
    m_fwd_error = 0;
    m_rot_error = 0;
    m_previous_fwd_error = 0;
    m_previous_rot_error = 0;
  }

  void stop()
  {
    set_left_motor_volts(0);
    set_right_motor_volts(0);
  }

  void begin()
  {
    stop();
  }

  /**
   * At each iteration of the main control loop we need to calculate
   * now outputs form the two position controllers - one for forward
   * motion, one for rotation.
   *
   * The current error increases by an amount determined by the speed
   * and the control loop interval.
   *
   * It is then decreased by the amount the robot has actually moved
   * in the previous loop interval.
   *
   * These changes are both done in the first line.
   *
   * After that we have a simple PD contoller.
   *
   * NOTE: the D-term constant is premultiplied in the config by the
   * loop frequency to save a little time.
   */
  float position_controller()
  {
    float increment = m_velocity * LOOP_INTERVAL;
    m_fwd_error += increment - robot_fwd_change();
    float diff = m_fwd_error - m_previous_fwd_error;
    m_previous_fwd_error = m_fwd_error;
    float output = FWD_KP * m_fwd_error + FWD_KD * diff;
    return output;
  }

  /**
   * The rotation controller is exactly like the forward controller
   * except that there is an additional error term from the steering.
   * All steering correction is done by treating the error term as an
   * angular velocity. Depending on your method of analysis, you might
   * also try feeding the steering corection back as an angular
   * acceleration.
   *
   * If you have a gyro, you can use the output from that instead of
   * the encoders.
   *
   * A separate controller calculates the steering adjustment term.
   */
  float angle_controller(float steering_adjustment)
  {
    float increment = m_omega * LOOP_INTERVAL;
    m_rot_error += increment - robot_rot_change();
    m_rot_error += steering_adjustment;
    float diff = m_rot_error - m_previous_rot_error;
    m_previous_rot_error = m_rot_error;
    float output = ROT_KP * m_rot_error + ROT_KD * diff;
    return output;
  }

  /**
   * Feed forward attempts to work out what voltage the motors would need
   * to run at the current speed and acceleration.
   *
   * Without this, the controller has a lot of work to do and will be
   * much harder to tune for good performance.
   *
   * The drive train is not symmetric and there is significant stiction.
   * If used with PID, a simpler, single value will be sufficient.
   *
   */

  float leftFeedForward(float speed)
  {
    static float oldSpeed = speed;
    float leftFF = speed * SPEED_FF;
    if (speed > 0)
    {
      leftFF += BIAS_FF;
    }
    else if (speed < 0)
    {
      leftFF -= BIAS_FF;
    }
    else
    {
      // No bias when the speed is 0
    }
    float acc = (speed - oldSpeed) * LOOP_FREQUENCY;
    oldSpeed = speed;
    float accFF = ACC_FF * acc;
    leftFF += accFF;
    return leftFF;
  }

  float rightFeedForward(float speed)
  {
    static float oldSpeed = speed;
    float rightFF = speed * SPEED_FF;
    if (speed > 0)
    {
      rightFF += BIAS_FF;
    }
    else if (speed < 0)
    {
      rightFF -= BIAS_FF;
    }
    else
    {
      // No bias when the speed is 0
    }
    float acc = (speed - oldSpeed) * LOOP_FREQUENCY;
    oldSpeed = speed;
    float accFF = ACC_FF * acc;
    rightFF += accFF;
    return rightFF;
  }

  /**
   * Calculate the outputs of the feedback and feedforward controllers
   * for both forward and rotation, and combine them to obtain drive
   * voltages for the left and right motors.
   */
  void update_controllers(float velocity, float omega, float steering_adjustment)
  {
    m_velocity = velocity;
    m_omega = omega;
    float pos_output = position_controller();
    float rot_output = angle_controller(steering_adjustment);
    float left_output = 0;
    float right_output = 0;
    left_output = pos_output - rot_output;
    right_output = pos_output + rot_output;

    float tangent_speed = m_omega * MOUSE_RADIUS * RADIANS_PER_DEGREE;
    float left_speed = m_velocity - tangent_speed;
    float right_speed = m_velocity + tangent_speed;
    float left_ff = leftFeedForward(left_speed);
    float right_ff = rightFeedForward(right_speed);
    if (m_feedforward_enabled)
    {
      left_output += left_ff;
      right_output += right_ff;
    }
    if (m_controller_output_enabled)
    {
      set_right_motor_volts(right_output);
      set_left_motor_volts(left_output);
    }
  }

  /**
   * Once the motor voltages have been calculated, they need to be converted
   * into suitable PWM values for the motor drivers.
   *
   * In this section, the calculations for that are done, taking into account
   * the available battery voltage and the limits of the PWM hardware.
   *
   * If there is not enough voltage available from the battery, the output
   * will just saturate and the motor will not get up to speed.
   *
   * Some people add code to light up an LED whenever the drive output is
   * saturated.
   */
  int pwm_compensated(float desired_voltage, float battery_voltage)
  {
    int pwm = MOTOR_MAX_PWM * desired_voltage / battery_voltage;
    return pwm;
  }
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

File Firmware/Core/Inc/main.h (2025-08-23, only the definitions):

#define LED1_Pin GPIO_PIN_13
#define LED1_GPIO_Port GPIOC
#define REC_L_Pin GPIO_PIN_0
#define REC_L_GPIO_Port GPIOC
#define REC_FL_Pin GPIO_PIN_1
#define REC_FL_GPIO_Port GPIOC
#define ENC_B1_Pin GPIO_PIN_0
#define ENC_B1_GPIO_Port GPIOA
#define ENC_B2_Pin GPIO_PIN_1
#define ENC_B2_GPIO_Port GPIOA
#define BAT_3V7_Pin GPIO_PIN_2
#define BAT_3V7_GPIO_Port GPIOA
#define BAT_7V4_Pin GPIO_PIN_3
#define BAT_7V4_GPIO_Port GPIOA
#define REC_R_Pin GPIO_PIN_4
#define REC_R_GPIO_Port GPIOA
#define REC_FR_Pin GPIO_PIN_5
#define REC_FR_GPIO_Port GPIOA
#define MOT_A1_Pin GPIO_PIN_6
#define MOT_A1_GPIO_Port GPIOA
#define MOT_A2_Pin GPIO_PIN_7
#define MOT_A2_GPIO_Port GPIOA
#define MOT_B1_Pin GPIO_PIN_0
#define MOT_B1_GPIO_Port GPIOB
#define MOT_B2_Pin GPIO_PIN_1
#define MOT_B2_GPIO_Port GPIOB
#define MOT_ENABLE_Pin GPIO_PIN_2
#define MOT_ENABLE_GPIO_Port GPIOB
#define B_KEY_Pin GPIO_PIN_12
#define B_KEY_GPIO_Port GPIOB
#define B_KEY_EXTI_IRQn EXTI15_10_IRQn
#define LED4_Pin GPIO_PIN_6
#define LED4_GPIO_Port GPIOC
#define LED3_Pin GPIO_PIN_7
#define LED3_GPIO_Port GPIOC
#define ENC_A1_Pin GPIO_PIN_8
#define ENC_A1_GPIO_Port GPIOA
#define ENC_A2_Pin GPIO_PIN_9
#define ENC_A2_GPIO_Port GPIOA
#define TR_FR_Pin GPIO_PIN_11
#define TR_FR_GPIO_Port GPIOA
#define TR_R_Pin GPIO_PIN_12
#define TR_R_GPIO_Port GPIOA
#define CS_Pin GPIO_PIN_2
#define CS_GPIO_Port GPIOD
#define LED2_Pin GPIO_PIN_3
#define LED2_GPIO_Port GPIOB
#define TR_L_Pin GPIO_PIN_4
#define TR_L_GPIO_Port GPIOB
#define TR_FL_Pin GPIO_PIN_5
#define TR_FL_GPIO_Port GPIOB
#define B_BOOT_Pin GPIO_PIN_8
#define B_BOOT_GPIO_Port GPIOB
#define B_BOOT_EXTI_IRQn EXTI9_5_IRQn

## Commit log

2025-04-29 updates on gyro
    [Metric - Spur gear 0.25M 60T 20PA 3FW ---S60N75H50L3N.SLDPRT, motor_gear.DXF, motor_gear.SLDDRW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]
2025-05-01 udates on design
    [Drive System.SLDASM, Motor gear.SLDPRT, Motor.SLDASM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]
2025-06-13 PCB created
    [BOM.csv, Drive System.SLDASM, holder.DXF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]
2025-08-04 Resource Updates
    [Drill_NPTH_Through.DRL, Drill_PTH_Through.DRL, Drill_PTH_Through_Via.DRL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]
2025-08-11 Gyro readings are live
2025-08-22 updated sensor

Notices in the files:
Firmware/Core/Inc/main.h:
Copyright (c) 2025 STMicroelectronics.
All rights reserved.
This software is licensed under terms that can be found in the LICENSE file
